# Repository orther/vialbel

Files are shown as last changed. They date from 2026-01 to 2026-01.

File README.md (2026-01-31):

# Vial Label Applicator

3D-printable semi-automated thermal label applicator for small vials. Applies wrap-around thermal labels (40mm x 20mm, NiimBot M2) to 3mL cylindrical vials (16mm diameter x 38.5mm tall).

## Key Specs

| Parameter | Value |
|---|---|
| Vial diameter | 16mm (22mm profile available) |
| Vial height | 38.5mm |
| Label size | 40mm x 20mm |
| Label position | 3mm from vial bottom |
| Material | ASA (Bambu Lab P1S) |
| Throughput | 2-3 seconds per vial |

## Project Structure

```
config.toml             - Parametric dimensions (profiles: default, 22mm)
src/                    - Parametric CAD scripts (Build123d, Python)
  config.py             - Config loader with profile support
  frame.py              - Main frame + assembly manifest generation
  peel_plate.py         - Label dispensing peel plate
  vial_cradle.py        - V-block vial holder
  tension_system.py     - Spool holder, dancer arm, guide roller bracket
  label_path.py         - Label routing simulation and validation
  validate_prints.py    - 3D print validation (manifold, overhang, wall thickness)
src/vcad/               - Parametric CAD scripts (vcad, Rust)
src/blender/            - Blender visualization and rendering
  import_assembly.py    - Import assembly via Blender MCP
  render_all.py         - Headless render script (3 camera presets)
models/
  components/           - Build123d-generated STL/3MF files
  vcad/                 - vcad-generated STL files
  assembly_manifest.json - Component positions (single source of truth)
  renders/              - Rendered assembly images
tests/                  - Integration tests (pytest)
.github/workflows/      - CI pipeline (Rust + Python + tests)
```

## Components

1. **Main Frame** — Base plate with mounting wall, pivot post, and mounting holes
2. **Peel Plate** — Label dispensing with 2mm radius peel edge
3. **Vial Cradle** — V-block holder with height positioning
4. **Tension System** — Spool holder, spring-loaded dancer arm, guide roller bracket
5. **Label Path** — Simulated routing: spool → dancer → guide → peel plate → vial

## Parametric Configuration

All dimensions are defined in `config.toml`. Switch vial sizes with profiles:

```bash
# Default 16mm vial
python src/peel_plate.py

# 22mm vial profile
python src/peel_plate.py --profile 22mm
```

Both Python (Build123d) and Rust (vcad) pipelines read from the same `config.toml`.

## Regenerating Models

### Build123d (precision parts)

```bash
python3 -m venv .venv && source .venv/bin/activate
pip install build123d

python src/frame.py              # Frame + assembly manifest
python src/peel_plate.py         # Peel plate
python src/vial_cradle.py        # Vial cradle
python src/tension_system.py     # Spool holder, dancer arm, guide roller bracket
python src/label_path.py         # Label path simulation + visualization STL
```

### vcad (rapid prototypes, Rust)

```bash
cargo run --manifest-path src/vcad/Cargo.toml
```

### Print Validation

```bash
pip install trimesh numpy rtree
python src/validate_prints.py
```

### Headless Rendering

```bash
blender --background --python src/blender/render_all.py -- \
    --output models/renders/ --resolution 1920x1080 --samples 128
```

Or use the convenience script:

```bash
./scripts/render.sh
```

## Testing

```bash
pip install pytest ruff
python -m pytest tests/ -v
```

Tests validate config loading, profile overrides, manifest structure, STL file existence, and code quality (ruff lint/format) — no build123d required.

## CI

GitHub Actions runs three jobs on push/PR to main:
- **Rust Check** — `cargo check` + `cargo clippy`
- **Python Lint** — `ruff check` + `ruff format --check`
- **Integration Tests** — pytest suite

## Documentation

- [Installation Guide](docs/installation-guide.md) — CAD environment setup
- [Print Settings](docs/print-settings.md) — Bambu Studio ASA profiles
- [Hardware BOM](docs/hardware-bom.md) — Non-printed parts list
- [Assembly Guide](docs/assembly-guide.md) — Step-by-step assembly
- [Calibration Guide](docs/calibration-guide.md) — First-time setup
- [Blender MCP Setup](docs/blender-mcp-setup.md) — Blender integration via MCP

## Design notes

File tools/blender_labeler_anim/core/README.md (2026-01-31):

# Core Modules

Shared infrastructure for the Blender label applicator animation system.

## Modules

- **constants.py** — Mechanical coordinates, radii, and label parameters
- **units.py** — Scene unit configuration (millimeters)
- **materials.py** — Material factory functions (label, backing, glass, metal)
- **cli.py** — CLI argument parsing for `blender -b -P script.py -- [args]`
- **render.py** — Render settings, output config, frame/animation rendering, MP4 encoding
- **generate_scene.py** — Base scene creation (camera, lights, ground, vial, rollers, CTRL empty)
- **geom_nodes_lib.py** — Geometry Nodes programmatic builders

## CTRL Empty

All animation is driven from custom properties on the `CTRL` empty:
- `feed_mm` — Label feed distance (0–200mm)
- `vial_rot_deg` — Vial rotation (0–360°)
- `dancer_deg` — Dancer arm angle (±30°)

## Usage

```python
import sys
sys.path.insert(0, '/path/to/tools/blender_labeler_anim')
from core.generate_scene import build_base_scene
from core.render import setup_render, render_animation
from core.cli import parse_args

args = parse_args()
objects = build_base_scene()
setup_render(engine=args.engine, samples=args.samples, resolution=tuple(args.resolution), fps=args.fps, frame_range=tuple(args.frames))
```

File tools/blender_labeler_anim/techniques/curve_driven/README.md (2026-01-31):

# Curve-Driven Label Routing

## What it demonstrates
The complete label/backing paper path through the applicator mechanism:
- Spool exit → dancer roller → guide roller → peel edge
- Peel separation: label continues to vial, backing wraps around peel radius and exits
- Feed visualization via curve trim/reveal driven by `CTRL.feed_mm`
- Dancer arm kinematics driven by `CTRL.dancer_deg`

## How it works
1. Waypoints from mechanical constants define the label path centerline
2. Roller wrap arcs are computed for dancer and guide rollers
3. At the peel edge, the path splits into backing exit and label exit curves
4. Geometry Nodes convert curves to ribbon meshes (Curve to Mesh + rectangle profile)
5. Trim/reveal GN modifier controls how much of each path is visible
6. Drivers on CTRL.feed_mm map feed distance to trim factor (0–1)

## How to run headless
```bash
blender -b -P tools/blender_labeler_anim/techniques/curve_driven/generate_and_render.py \
  -- --out tools/blender_labeler_anim/techniques/curve_driven/output \
  --frames 1 120 --fps 24 --samples 32
```

## Outputs
- `output/frame_0001.png` through `frame_0120.png` — rendered PNG frames
- `output/animation.mp4` — if `--encode-mp4` is passed and ffmpeg is available

## Key parameters
- `--frames 1 N` — number of frames (more = smoother, slower render)
- `--samples N` — Cycles samples (lower = faster, noisier)
- `--engine BLENDER_EEVEE_NEXT` — faster rendering alternative
- In script: modify `keyframe_ctrl()` to change animation timing

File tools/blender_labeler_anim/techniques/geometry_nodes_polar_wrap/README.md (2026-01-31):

# Wrap Technique B: Pure Geometry Nodes Polar Wrap

## What it demonstrates
A coordinate-space deformation that morphs a flat label strip into a cylindrical
wrap around the vial — entirely within Geometry Nodes, with no separate geometries.

## How it works
1. A flat, subdivided label mesh is created at the peel edge position
2. A Geometry Nodes modifier performs polar coordinate mapping:
   - Each vertex's X position (along the wrap direction) maps to an angle:
     `angle = (x / wrap_length) * wrap_max_angle * wrap_factor`
   - New positions computed relative to vial center:
     `x' = vial_cx + (r + eps) * cos(start_angle - angle)`
     `z' = vial_cz + (r + eps) * sin(start_angle - angle)`
     `y' = vial_cy + original_y`
3. A blend zone provides smooth transition from flat-at-peel to cylindrical:
   - Vertices near the current wrap front smoothly interpolate between flat and wrapped
   - Vertices beyond the wrap extent remain at the peel edge (or are hidden)
4. The `Wrap Factor` input (0–1) is driven by `CTRL.vial_rot_deg / 270`

## How to run headless
```bash
blender -b -P tools/blender_labeler_anim/techniques/geometry_nodes_polar_wrap/generate_and_render.py \
  -- --out tools/blender_labeler_anim/techniques/geometry_nodes_polar_wrap/output \
  --frames 1 120 --fps 24 --samples 32
```

## Outputs
- `output/frame_0001.png` through `frame_0120.png`
- `output/animation.mp4` (with `--encode-mp4`)

## Key parameters
- `Wrap Factor`: 0 = fully flat, 1 = fully wrapped (270°)
- `Blend Zone`: transition width in mm (default 5mm) — controls smoothness
- Surface offset: 0.3mm above vial radius
- Mesh resolution: 100 segments along wrap, 6 across width

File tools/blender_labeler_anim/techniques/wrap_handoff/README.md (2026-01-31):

# Wrap Technique A: Two-Geometry Handoff

## What it demonstrates
A deterministic "engineering visualization" of label wrapping using two separate
geometries: a flat label strip near the peel edge and a pre-shaped cylindrical
patch on the vial surface. As wrapping progresses, the wrapped patch is revealed
while the flat strip is hidden — creating the illusion of continuous wrapping.

## How it works
1. **Flat label strip**: A subdivided planar mesh positioned between the peel edge
   and vial contact point, with a slight arc for visual appeal.
2. **Wrapped label patch**: A cylindrical mesh pre-shaped to conform to the vial
   surface (offset 0.3mm above to avoid z-fighting), covering up to 270°.
3. **Handoff mechanism**: Geometry Nodes modifiers on each mesh use vertex index
   ratio as a position proxy. A Factor input (driven by `CTRL.vial_rot_deg`)
   controls which portions are visible:
   - Wrapped patch: vertices with index ratio < factor are kept (progressive reveal)
   - Flat strip: vertices with index ratio > factor are kept (progressive hide)
4. **Vial rotation**: The vial's Y rotation is driven by `CTRL.vial_rot_deg`,
   so the wrapped patch stays aligned as the vial turns.

## How to run headless
```bash
blender -b -P tools/blender_labeler_anim/techniques/wrap_handoff/generate_and_render.py \
  -- --out tools/blender_labeler_anim/techniques/wrap_handoff/output \
  --frames 1 120 --fps 24 --samples 32
```

## Outputs
- `output/frame_0001.png` through `frame_0120.png`
- `output/animation.mp4` (with `--encode-mp4`)

## Key parameters
- Wrap coverage: 270° (set in `constants.LABEL_WRAP_ANGLE`)
- Surface offset: 0.3mm above vial radius (prevents z-fighting)
- Mesh resolution: 80 segments around circumference, 4 along axis

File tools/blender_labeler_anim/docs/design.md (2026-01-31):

# Design: Blender Label Applicator Animation System

## Overview

A headless, scripted Blender animation system for visualizing a mechanical vial label applicator. The system generates all geometry, materials, and animation from Python scripts with no manual Blender interaction required.

## Architecture

### Core Layer (`core/`)
Shared infrastructure used by all techniques:
- **Scene generation**: Camera, lighting, ground plane, mechanical components (vial, rollers, peel plate)
- **CTRL Empty**: Single animation controller with `feed_mm`, `vial_rot_deg`, `dancer_deg` custom properties
- **Materials**: Principled BSDF-based materials for label, backing, glass, metal
- **Render pipeline**: Cycles/EEVEE-Next configuration, PNG output, optional MP4 encoding
- **Geometry Nodes library**: Programmatic node group construction (curve-to-ribbon, trim/reveal)

### Technique Layer (`techniques/`)
Three independent implementations, each self-contained:

1. **Curve-Driven** — Label/backing paths as Blender curves with ribbon mesh via GN
2. **Wrap Handoff** — Two-geometry system: flat strip near peel edge + cylindrical patch on vial
3. **Geometry Nodes Polar Wrap** — Pure GN coordinate deformation from flat to cylindrical

### Control Flow
```
CTRL.feed_mm ──► Curve trim/reveal ──► Label feed visualization
CTRL.vial_rot_deg ──► Vial rotation ──► Wrap amount (handoff or polar)
CTRL.dancer_deg ──► Dancer arm rotation ──► Tension arm kinematics
```

All motion is driven via Blender drivers referencing CTRL properties. No simulation or physics; fully deterministic.

## Determinism Guarantee

- No cloth/soft-body simulation
- No random seeds in geometry generation
- All positions computed from parametric equations
- Curves defined by explicit control points
- Geometry Nodes use deterministic operations only
- Repeated runs with same parameters produce identical output

## Coordinate System

- X: left(-) to right(+)
- Y: back(-) to front(+)
- Z: bottom(0) to top(+)
- Units: millimeters (scene scale = 0.001)

## Rendering

- Default engine: Cycles (GPU via Metal on macOS)
- Fallback: EEVEE-Next for faster previews
- Output: PNG frames with optional ffmpeg MP4 encoding
- Headless: `blender -b -P script.py -- [args]`

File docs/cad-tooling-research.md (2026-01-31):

# Programmatic CAD Tooling Research

**Date:** 2026-01-29
**Purpose:** Evaluate Python-scriptable, headless CAD tools for generating 3D-printable mechanical parts (peel plates, V-block cradles, spring-loaded tension arms, frames with heat-set insert recesses) targeting ASA on a Bambu Lab P1S.

**Key requirements:** Fillets/chamfers (2mm radius edges), clean STL/3MF export, fully headless operation, parametric design.

---

## Tool Comparison Matrix

| Criteria (1-5) | CadQuery | Build123d | SolidPython2 | OpenSCAD | FreeCAD (Python) |
|---|---|---|---|---|---|
| Headless/CLI reliability | 5 | 5 | 4 | 4 | 2 |
| Parametric design support | 5 | 5 | 4 | 4 | 4 |
| STL/3MF export | 5 | 5 | 3 | 3 | 4 |
| Fillets, chamfers, smooth curves| 5 | 5 | 2 | 2 | 5 |
| Boolean operations | 5 | 5 | 4 | 4 | 5 |
| Documentation quality | 4 | 4 | 3 | 4 | 3 |
| Ease of installation (pip) | 4 | 4 | 5 | 3 | 1 |
| Community/maintenance activity  | 4 | 4 | 2 | 4 | 5 |
| **Total** | **37** | **37** | **27** | **28** | **29** |

---

## Detailed Evaluation

### 1. CadQuery

**GitHub:** https://github.com/CadQuery/cadquery
**Install:** `pip install cadquery` (Python 3.9-3.12, 3.13 partial)
**Kernel:** Open CASCADE Technology (OCCT) via OCP bindings

**Pros:**
- Built from the ground up for headless, scriptable CAD -- no GUI dependency whatsoever
- Full BREP kernel (OCCT) provides native, high-quality fillets and chamfers on any edge
- Exports STL, STEP, 3MF, DXF, VRML, AMF natively
- Fluent/chained API for building parametric models
- Strong ecosystem: cq-kit, cqparts, CQ-editor for optional visualization
- Active development; pip-installable with binary wheels on all major platforms
- Tolerance control on STL tessellation for print quality tuning

**Cons:**
- Fluent/method-chaining API can be hard to debug -- stack traces are opaque
- String-based selectors (e.g., `">Z"`) lack IDE autocomplete
- cadquery-ocp wheels are large (~200MB) and only cover specific Python versions
- conda was historically the recommended install path; pip support is newer and occasionally has dependency issues

**Best for:** Production headless workflows, CI/CD pipelines, batch part generation

---

### 2. Build123d

**GitHub:** https://github.com/gumyr/build123d
**Install:** `pip install build123d` (Python 3.10-3.13)
**Kernel:** OCCT via the same OCP bindings as CadQuery

**Pros:**
- More Pythonic API than CadQuery -- uses context managers instead of method chaining
- Dual modeling: both builder-pattern (feature stack) and algebra-mode (CSG tree), combinable
- Enums replace string selectors -- full IDE autocomplete and type checking
- Native fillets/chamfers with intuitive edge selection (`group_by`, `filter_by`)
- STL and 3MF export via `Mesher` class with tolerance control
- Extensible via standard Python classes (no monkey-patching)
- Interoperable with CadQuery objects (shared OCP wrapper)
- Actively maintained by gumyr (original CadQuery contributor)

**Cons:**
- Younger project -- some APIs may still change
- Smaller community and fewer third-party examples than CadQuery
- Same large OCP binary wheel dependency
- Documentation is good but less battle-tested than CadQuery's

**Best for:** New projects where a modern, Pythonic API and strong IDE support matter

---

### 3. SolidPython2

**GitHub:** https://github.com/SolidCode/SolidPython
**Install:** `pip install solidpython2` (Python 3.7+)
**Kernel:** Generates OpenSCAD code; requires OpenSCAD installed for rendering

**Pros:**
- Trivial pip install (pure Python, no binary dependencies)
- Full Python language features for parametric design (loops, functions, classes)
- BOSL2 library integration for advanced shapes
- Lightweight -- just generates `.scad` files

**Cons:**
- **No native fillets/chamfers** -- inherits all of OpenSCAD's CGAL limitations
- Fillets require Minkowski sum (extremely slow on complex geometry) or manual construction
- Requires OpenSCAD as an external runtime dependency for STL export
- Only mesh-based export (STL); no STEP or native 3MF
- Low download numbers (188/week); beta status
- Two-step workflow: generate .scad, then invoke OpenSCAD to render
- OpenSCAD rendering can be very slow for complex models

**Best for:** Simple parts where OpenSCAD familiarity exists; not suitable for parts requiring fillets

---

### 4. OpenSCAD (Direct)

**Website:** https://openscad.org
**Install:** System package or download; no pip install
**Kernel:** CGAL (CSG-based)

**Pros:**
- Mature, well-documented scripting language purpose-built for parametric CAD
- Headless CLI mode: `openscad -o output.stl input.scad`
- Large community, many existing libraries (BOSL2, NopSCADlib, etc.)
- Customizer for parametric variants
- Good for simple mechanical parts and enclosures

**Cons:**
- **No native fillet or chamfer operations** -- fundamental limitation of CSG/CGAL kernel
- Workarounds (Minkowski sum) are impractical for complex geometry (hours/days to compute)
- Not Python -- custom language with limited programming constructs
- STL export only (no STEP, limited 3MF via external tools)
- Cannot represent smooth curves natively; everything is mesh-approximated from the start
- 2mm radius edge fillets on complex parts would be extremely difficult

**Best for:** Simple box/cylinder CSG parts; poor fit for parts needing fillets

---

### 5. FreeCAD (Python Scripting)

**GitHub:** https://github.com/FreeCAD/FreeCAD
**Install:** System install required; no pip install of the CAD kernel
**Kernel:** OCCT (same as CadQuery/Build123d)

**Pros:**
- Full professional CAD kernel with excellent fillet/chamfer/boolean support
- Massive feature set: PartDesign, Part, Draft, Sketcher, FEM, CAM
- Large, active community; well-funded open source project
- Can theoretically do anything a commercial CAD package can

**Cons:**
- **Headless operation is unreliable** -- many modules silently depend on GUI components
- May require `xvfb` (virtual framebuffer) on Linux for headless operation
- No pip install -- requires system FreeCAD installation and manual Python path configuration
- API is verbose and not Pythonic; documentation for scripting is scattered
- Different Python version between FreeCAD's bundled interpreter and your venv causes import errors
- Fragile setup for CI/CD or automated pipelines

**Best for:** Interactive CAD work with Python macros; poor fit for headless automation

---

## MCP Server Findings

Several MCP (Model Context Protocol) servers exist for CAD integration with AI assistants:

### FreeCAD MCP Servers

| Server | GitHub | Notes |
|---|---|---|
| **contextform/freecad-mcp** | https://github.com/contextform/freecad-mcp | Most feature-rich: 13 PartDesign ops (Pad, Fillet, Chamfer, Holes, Patterns) + 18 Part ops (Booleans, Transforms). Open source. |
| **neka-nat/freecad-mcp** | https://github.com/neka-nat/freecad-mcp | Control FreeCAD from Claude Desktop via uv. Simpler scope. |
| **lucygoodchild/freecad-mcp-server** | https://github.com/lucygoodchild/freecad-mcp-server | Basic geometry creation, booleans, document management. Cross-platform. |
| **bonninr/freecad_mcp** | https://github.com/bonninr/freecad_mcp | Claude/Cursor integration for prompt-assisted CAD design. |
| **jango-blockchained/mcp-freecad** | https://github.com/jango-blockchained/mcp-freecad | Multiple AI provider support, robust connection methods. |

### OpenSCAD MCP Servers

| Server | GitHub | Notes |
|---|---|---|
| **quellant/openscad-mcp** | https://github.com/quellant/openscad-mcp | Production-ready FastMCP server for OpenSCAD rendering. v1.0.0 (Aug 2025). |
| **jhacksman/OpenSCAD-MCP-Server** | https://github.com/jhacksman/OpenSCAD-MCP-Server | Text/image to 3D model generation. Multi-view reconstruction. 102 stars. |

### No CadQuery/Build123d MCP Servers Found

There are currently no MCP servers specifically for CadQuery or Build123d. However, since both are pure Python libraries, an MCP server wrapping them would be straightforward to build -- the LLM would generate CadQuery/Build123d Python code directly, which is already a well-documented pattern ("Text-to-CadQuery").

---

## Recommendation

### Primary: **Build123d**

Build123d is the strongest choice for this use case:

1. **Fillets/chamfers are first-class operations** -- 2mm radius edges on peel plates, smooth V-block cradle profiles, and rounded frame features are trivial with `fillet()` and `chamfer()` on selected edges.

2. **Fully headless** -- pure Python library, no GUI dependency, no xvfb hacks. Works in scripts, CI/CD, and automated pipelines.

3. **Clean export** -- native STL and 3MF export with tessellation tolerance control. 3MF is preferred for Bambu Lab P1S (Bambu Studio natively uses 3MF).

4. **Modern Pythonic API** -- context managers, enums, type hints, and IDE autocomplete make parametric design readable and maintainable. Dual builder/algebra modes suit different part design styles.

5. **Same OCCT kernel** as CadQuery and FreeCAD -- no compromises on geometric quality.

6. **pip installable** -- `pip install build123d` with binary wheels.

### Fallback: **CadQuery**

If Build123d's newer API causes issues or a specific feature is missing, CadQuery is a drop-in alternative sharing the same OCCT kernel. The ecosystem is larger and more battle-tested. Objects can be transferred between the two libraries.

### Not Recommended for This Use Case

- **SolidPython2/OpenSCAD** -- The lack of native fillets makes 2mm radius edges on complex parts impractical. The CGAL kernel cannot handle the geometry requirements.
- **FreeCAD scripting** -- Headless operation is too fragile for reliable automated part generation.

### MCP Integration Path

No existing MCP server covers CadQuery/Build123d, but building one would be straightforward since the tools are already Python-native. For immediate MCP-assisted CAD, **contextform/freecad-mcp** is the most capable option, though it requires a FreeCAD installation. The recommended approach is to use Build123d directly in Python scripts, potentially wrapping it in a custom MCP server later if conversational CAD design is desired.

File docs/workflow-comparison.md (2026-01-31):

# Workflow Comparison

Three CAD tools available for the vial label applicator project, each with different strengths.

## Tool Summary

| | Build123d | vcad | Blender MCP |
|---|---|---|---|
| **Role** | Precision parts | Rapid prototyping | Visualization & rendering |
| **Language** | Python | Rust | Python (bpy) |
| **Geometry** | BREP (exact) | Mesh (approximate) | Mesh + modifiers |
| **Fillets** | Native | None | Bevel modifier |
| **Export** | STL, 3MF | STL, GLB | Any format |
| **AI integration** | Script generation | Agent-friendly API | MCP server |
| **Maturity** | Production | v0.1.0 | Production |

## Recommended Workflow

### For manufacturing (3D printing)
Use **Build123d**. BREP geometry ensures exact dimensions. Fillets and precise edge treatments are critical for functional parts that need to fit together.

```
Build123d script → STL/3MF → Bambu Studio → Print
```

### For rapid iteration
Use **vcad**. Fast compile times, simple API. Good for testing layout changes and basic geometry before committing to Build123d precision scripts.

```
vcad Rust script → STL → Quick preview
```

### For visualization and rendering
Use **Blender MCP**. Import STL files from either tool, apply materials, set up lighting, and produce product renders — all driven by Claude.

```
Build123d/vcad → STL → Blender MCP import → Materials → Render
```

### Full pipeline
```
1. Prototype with vcad (quick geometry)
2. Refine with Build123d (precision parts)
3. Visualize with Blender MCP (renders, assembly views)
```

## File Locations

| Tool | Source | Output |
|---|---|---|
| Build123d | `src/*.py` | `models/components/` |
| vcad | `src/vcad/src/*.rs` | `models/vcad/` |
| Blender | `src/blender/*.py` | Via Blender MCP |

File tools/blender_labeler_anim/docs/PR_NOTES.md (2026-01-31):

# PR Notes

## chore/blender-labeler-core

### Summary
Core scaffolding for the Blender label applicator animation system.

### Changes
- Created `tools/blender_labeler_anim/` directory structure
- Implemented shared core modules:
  - `constants.py` — Mechanical coordinates and parameters
  - `units.py` — Scene unit configuration (mm)
  - `materials.py` — Material factories
  - `cli.py` — CLI argument parsing
  - `render.py` — Render configuration and execution
  - `generate_scene.py` — Base scene builder
  - `geom_nodes_lib.py` — Geometry Nodes helpers
- Added documentation: design.md, troubleshooting.md

### How to Run
```bash
# Verify core modules load in Blender
blender -b -P tools/blender_labeler_anim/core/generate_scene.py
```

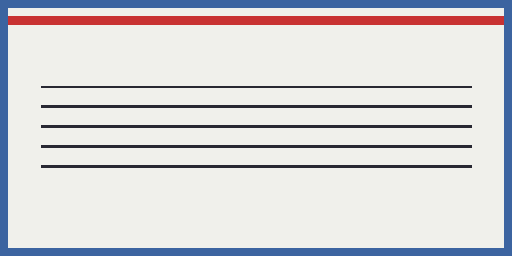
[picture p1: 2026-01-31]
tools/blender_labeler_anim/assets/label_texture.png

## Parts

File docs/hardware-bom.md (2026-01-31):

# Hardware Bill of Materials

All non-printed hardware required for assembly.

## Fasteners

| Item | Spec | Qty | Notes |
|---|---|-----|---|
| Socket head cap screw | M3 x 8mm | 8 | |
| Socket head cap screw | M3 x 12mm | 4 | |
| Heat-set insert | M3, 4mm OD x 5mm depth | 8 | McMaster 94459A130 or CNC Kitchen standard |
| Washer | M3 | 12 | |
| Hex nut | M3 | 4 | For adjustment slots |

## Springs

| Item | Spec | Qty | Notes |
|---|---|-----|---|
| Extension spring | ~6mm OD x 20mm length, light tension | 1 | For dancer arm |

## Bearings

| Item | Spec | Qty | Notes |
|---|---|-----|---|
| 608 bearing | 8mm ID x 22mm OD x 7mm | 2 | Dancer arm roller and guide roller |

## Pins

| Item | Spec | Qty | Notes |
|---|---|-----|---|
| Steel dowel pin | 8mm x 20mm | 2 | Bearing pins |
| Steel dowel pin | 8mm x 50mm | 1 | Dancer arm pivot |

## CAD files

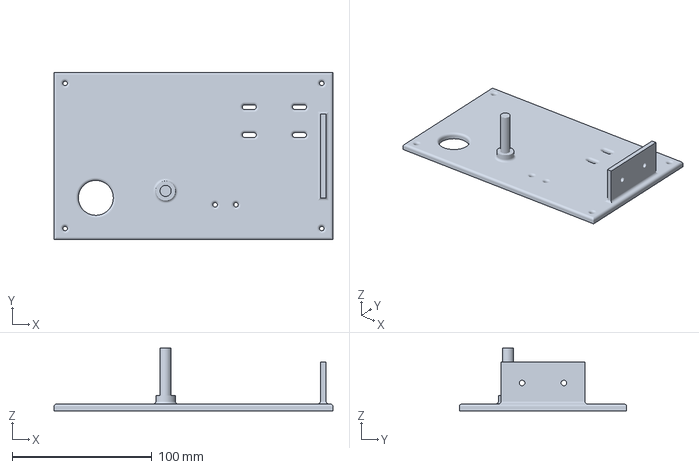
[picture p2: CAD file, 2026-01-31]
models/components/main_frame.3mf
200.0 x 120.0 x 45.0 mm

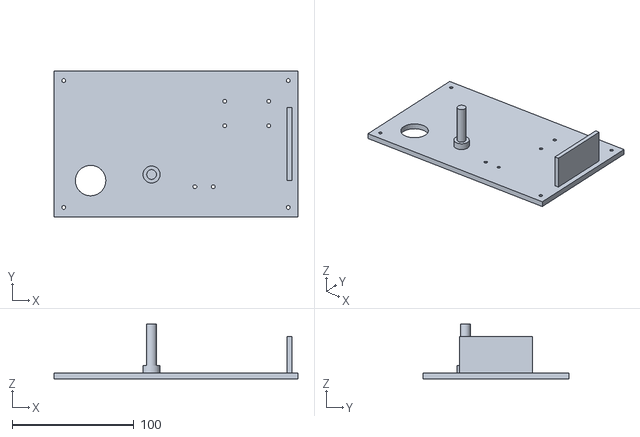
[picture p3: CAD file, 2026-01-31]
models/vcad/main_frame.stl
200.0 x 120.0 x 45.0

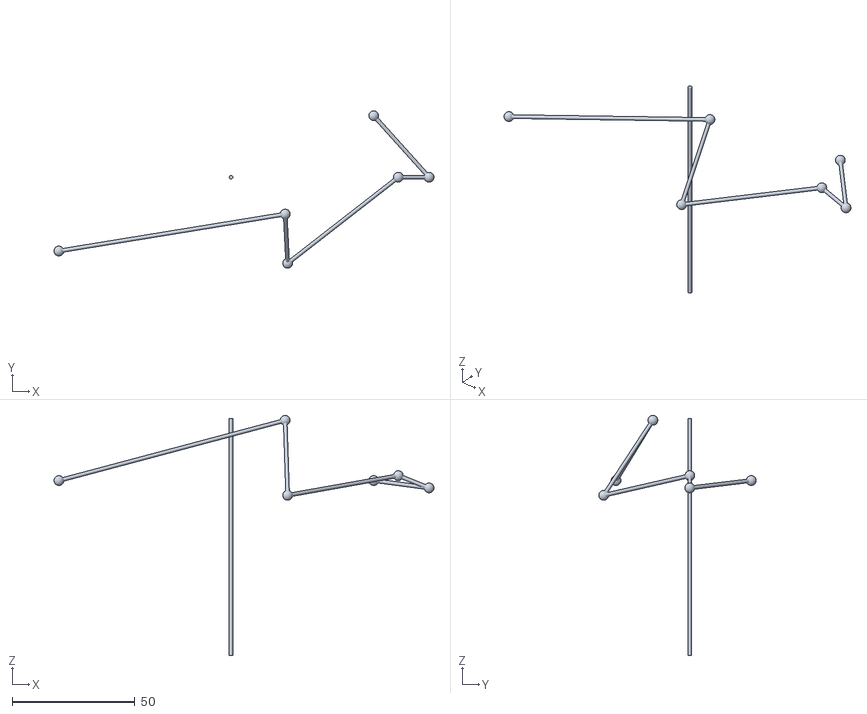
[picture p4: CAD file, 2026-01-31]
models/components/label_path.stl
154.5 x 64.0 x 97.7

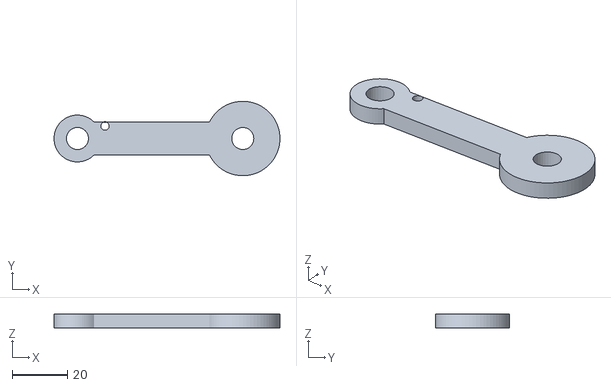
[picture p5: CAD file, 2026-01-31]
models/vcad/dancer_arm.stl
82.0 x 27.0 x 5.00

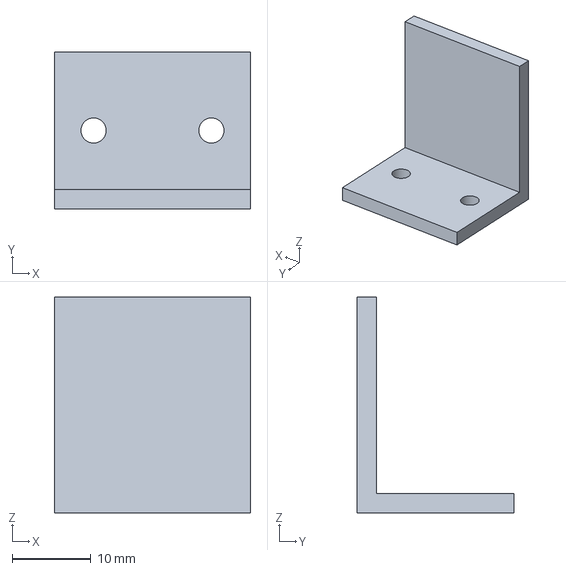
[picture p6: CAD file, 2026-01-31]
models/components/guide_roller_bracket.3mf
25.0 x 20.0 x 27.5 mm

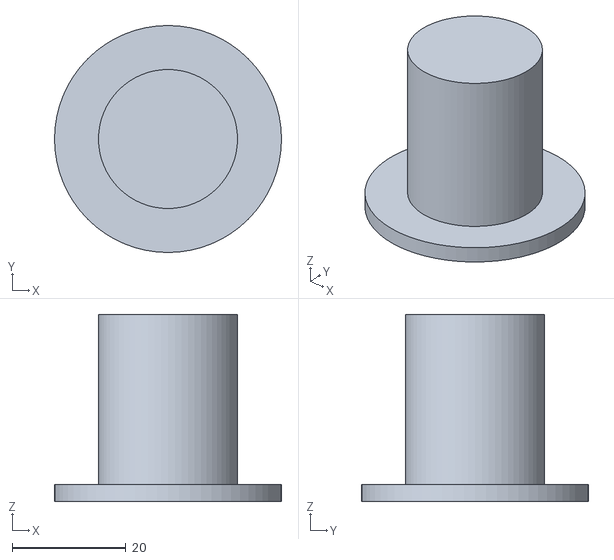
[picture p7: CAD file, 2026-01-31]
models/vcad/spool_holder.stl
40.0 x 40.0 x 33.0

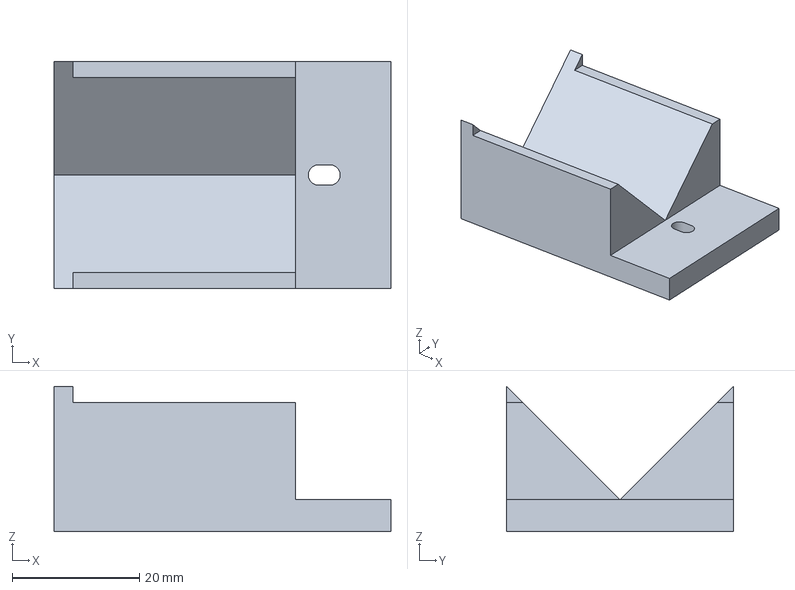
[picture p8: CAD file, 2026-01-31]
models/components/vial_cradle.3mf
53.0 x 35.6 x 22.8 mm

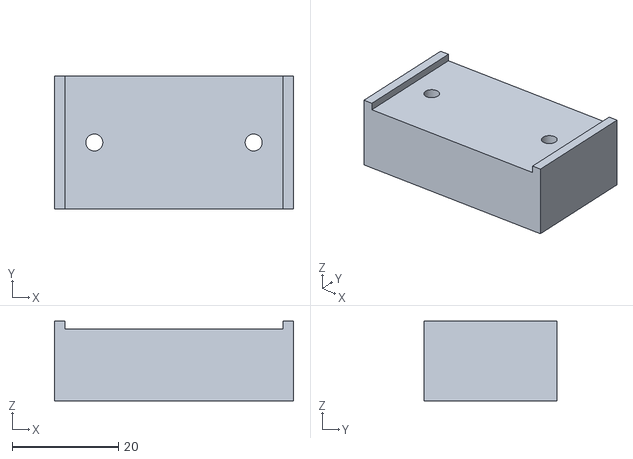
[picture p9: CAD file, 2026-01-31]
models/vcad/peel_plate.stl
45.0 x 25.0 x 15.0

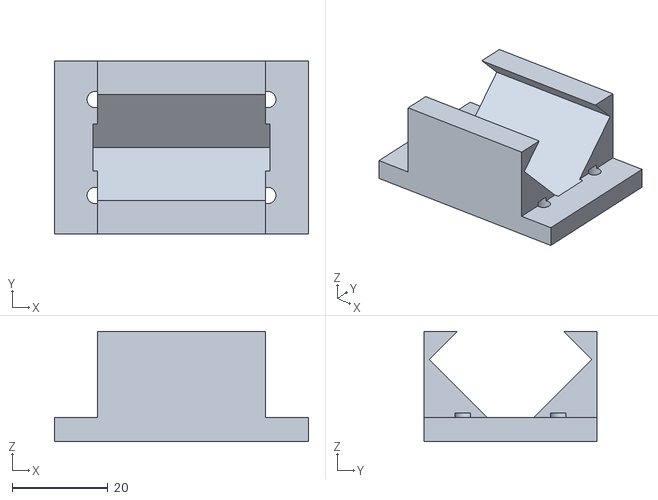
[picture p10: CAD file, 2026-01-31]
models/vcad/vial_cradle.stl
53.0 x 36.0 x 23.0

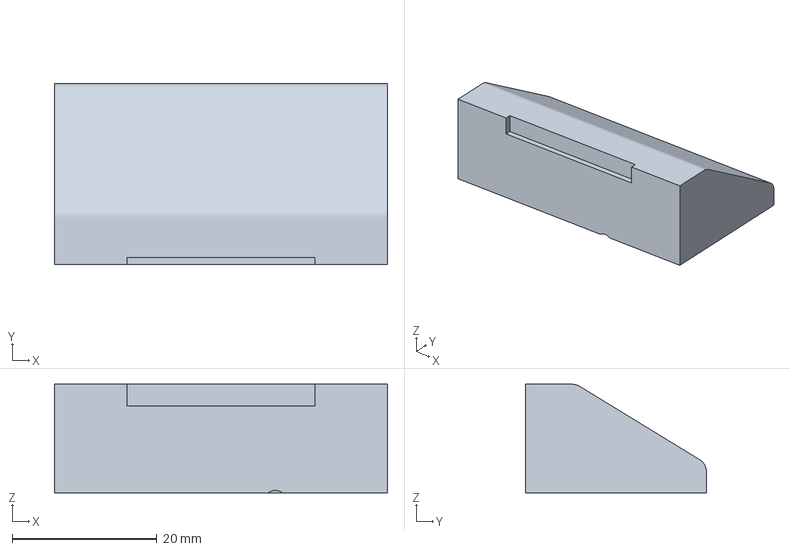
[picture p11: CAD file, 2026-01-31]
models/components/peel_plate.3mf
46.0 x 25.0 x 15.0 mm

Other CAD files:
models/vcad/guide_roller_bracket.stl
models/components/spool_holder.3mf
models/components/dancer_arm.stl
models/components/guide_roller_bracket.stl
models/components/peel_plate.stl
models/components/spool_holder.stl
models/components/vial_cradle.stl

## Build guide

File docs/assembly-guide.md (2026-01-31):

# Assembly Guide

## Prerequisites

- All parts printed per [print-settings.md](print-settings.md)
- All hardware from [hardware-bom.md](hardware-bom.md)
- Soldering iron with M3 insert tip

## Steps

### 1. Install Heat-Set Inserts

Set soldering iron to 220C (appropriate for ASA). Press each M3 heat-set insert into the frame mounting holes. Allow to cool before proceeding.

### 2. Mount Spool Holder

Attach the spool holder to the frame base using M3 x 8mm screws.

### 3. Install Dancer Arm Pivot

Press the 8mm x 50mm steel dowel pin into the dancer arm pivot hole on the frame.

### 4. Attach Dancer Arm

Slide the dancer arm onto the pivot pin. Install the 608 bearing on an 8mm x 20mm dowel pin and insert into the dancer arm roller position. Attach the extension spring between the dancer arm and the frame anchor point.

### 5. Mount Guide Roller Bracket

Install the second 608 bearing on the remaining 8mm x 20mm dowel pin. Mount the guide bracket to the frame using M3 x 12mm screws and washers.

### 6. Mount Peel Plate

Attach the peel plate to the frame wall using M3 x 8mm screws.

### 7. Position Vial Cradle

Place the vial cradle on the adjustment slots. Secure loosely with M3 x 12mm screws, hex nuts, and washers. Final position is set during calibration.

### 8. Thread Label Path

Route the label backing paper through the following path:

```
Spool --> Dancer arm roller --> Guide roller --> Peel plate
```

The label face should be oriented outward (away from the peel plate surface) so labels separate at the peel edge.

### 9. Test

Feed a label strip through the path and verify smooth travel before loading a full spool. Proceed to [calibration-guide.md](calibration-guide.md).

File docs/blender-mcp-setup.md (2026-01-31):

# Blender MCP Setup

Connect Blender to Claude Code for AI-driven 3D visualization, assembly, and rendering.

## Prerequisites

- Blender 4.0+ (installed via `brew install --cask blender`)
- Python 3.10+ with `uvx` (`pip install uv` or `brew install uv`)

## 1. Add MCP Server to Claude Code

```bash
claude mcp add blender -- uvx blender-mcp
```

This registers the blender-mcp server so Claude can call Blender tools.

## 2. Install Blender Addon

1. Download `addon.py` from [blender-mcp](https://github.com/ahujasid/blender-mcp)
2. Open Blender → Edit → Preferences → Add-ons
3. Click "Install..." and select the downloaded `addon.py`
4. Enable the checkbox for "Interface: Blender MCP"

## 3. Connect

1. Open Blender
2. Press `N` to open the sidebar → find the "BlenderMCP" tab
3. Click "Connect to Claude"
4. Start a Claude Code session — Blender tools will be available

## Available Tools

| Tool | Description |
|---|---|
| `execute_blender_code` | Run arbitrary Python/bpy code in Blender |
| `get_scene_info` | Get current scene objects and properties |
| `get_object_info` | Get details about a specific object |
| `get_viewport_screenshot` | Capture current viewport as image |
| `set_material` | Apply materials to objects |
| `get_polyhaven_assets` | Browse PolyHaven material/model library |

## Workflow Scripts

Two scripts in `src/blender/` are designed to be executed via `execute_blender_code`:

- **`import_assembly.py`** — Imports all STL components at correct assembly positions with color-coded materials
- **`render_setup.py`** — Sets up camera, three-point lighting, and Cycles render settings for product photography

## Usage Example

From Claude Code, after Blender is connected:

1. Ask Claude to import the assembly: executes `import_assembly.py` via MCP
2. Ask Claude to set up rendering: executes `render_setup.py` via MCP
3. Ask Claude to capture a screenshot: uses `get_viewport_screenshot`
4. Ask Claude to modify materials or positions: uses `execute_blender_code`

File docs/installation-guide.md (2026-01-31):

# Installation Guide

## Requirements

- Python 3.10+ (tested with 3.13)
- pip

## Setup

```bash
python3 -m venv .venv
source .venv/bin/activate
pip install build123d
```

## Verify

```bash
python src/test_cad_setup.py
```

Should output bounding box dimensions and export STL/3MF files to `models/test/`.

## Tooling

- **Build123d** (v0.10.0) - Parametric CAD library using OCCT kernel
- Exports STL and 3MF (native format for Bambu Studio)
- See [cad-tooling-research.md](cad-tooling-research.md) for selection rationale

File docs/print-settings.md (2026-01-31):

# Print Settings

Bambu Studio profile for ASA filament on a Bambu Lab P1S.

## Layer and Structure

| Setting | Functional Parts | Non-Critical Parts |
|---|---|---|
| Layer height | 0.20mm | 0.28mm |
| Walls | 4 minimum | 4 minimum |
| Infill | 40% gyroid | 20% gyroid |

## Adhesion and Enclosure

- **Brim**: Enabled, 5mm width for warping prevention
- **Enclosure**: Required for ASA (P1S enclosure panels must be installed)

## Temperature

| Setting | Range | Recommended |
|---|---|---|
| Nozzle | 240-260C | 250C |
| Bed | 100-110C | 105C |

## Speed and Cooling

- **Print speed**: 60-80mm/s
- **First layer speed**: 20mm/s
- **Part cooling fan**: 30-50% after first layer

## ASA Shrinkage

ASA shrinks 0.4-0.7% during cooling. All part dimensions in this project account for this shrinkage. Do not apply additional scaling in the slicer.

## Print Orientation by Component

| Component | Orientation | Notes |
|---|---|---|
| Peel plate | Flat side down | Peel edge faces up for smooth finish |
| Vial cradle | V-groove facing up | |
| Spool holder | Flange down | |
| Dancer arm | Flat on bed | |
| Guide bracket | L-shape vertical wall up | |
| Main frame | Flat base down | May need to split if exceeding 256mm build volume |

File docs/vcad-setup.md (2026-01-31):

# vcad Setup

Rust-based parametric CSG modeling for rapid prototyping of vial applicator components.

## Prerequisites

- Rust toolchain (install via `curl --proto '=https' --tlsv1.2 -sSf https://sh.rustup.rs | sh`)
- CMake and Ninja (`brew install cmake ninja`)

## Building

```bash
cargo build --manifest-path src/vcad/Cargo.toml
```

## Generating Models

```bash
cargo run --manifest-path src/vcad/Cargo.toml
```

Outputs STL files to `models/vcad/`:
- `peel_plate.stl` — Simplified peel plate (box body, no wedge profile or fillets)
- `vial_cradle.stl` — V-block cradle with angled cut
- `main_frame.stl` — Base plate with wall, pivot post, mounting holes

## vcad vs Build123d

| Feature | vcad | Build123d |
|---|---|---|
| Language | Rust | Python |
| Kernel | Manifold (mesh) | OCCT (BREP) |
| Fillets | No native support | Full BREP fillets |
| Precision | Mesh approximation | Mathematically exact |
| Export | STL, GLB, USD, STEP | STL, 3MF, STEP |
| AI workflow | Designed for agents | Standard Python |

## Limitations

- No native fillets or chamfers (mesh-based geometry)
- No loft or sweep operations
- V-groove approximated with rotated box cut (not trigonometric profile)
- Mounting slots simplified to round holes
- v0.1.0 — early-stage library with limited documentation

## Project Structure

```
src/vcad/
├── Cargo.toml          # Dependencies (vcad 0.1.0)
├── src/
│   ├── main.rs         # Entry point, builds all components
│   ├── peel_plate.rs   # Peel plate CSG
│   ├── vial_cradle.rs  # Vial cradle CSG
│   └── frame.rs        # Main frame CSG
```

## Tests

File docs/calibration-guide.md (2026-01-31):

# Calibration Guide

First-time setup after assembly. Refer to [assembly-guide.md](assembly-guide.md) if not yet assembled.

## 1. Adjust Vial Cradle Position

Slide the vial cradle along its adjustment slots until the label exit point on the peel plate aligns with the vial surface when a vial is seated in the cradle. Tighten the M3 hex nuts once positioned.

## 2. Adjust Dancer Arm Spring Tension

The spring should be:
- **Light enough** to allow the backing paper to feed freely without excessive drag.
- **Firm enough** to maintain consistent tension and prevent slack in the label path.

If the spring is too stiff, hook it to a lower anchor point or replace with a lighter spring.

## 3. Test Label Peel

Feed backing paper through the full path. Pull the backing paper past the peel plate edge and verify that labels separate cleanly from the backing at the peel edge. If labels do not peel, check that:
- The peel plate edge is sharp and smooth (sand lightly if needed).
- The backing paper wraps tightly around the peel edge with sufficient angle.

## 4. Height Check

Place a vial in the cradle. Verify that the bottom edge of the presented label sits approximately 3mm from the bottom of the vial. Adjust cradle position vertically if needed.

## 5. Width Check

Verify that the label tracks centered within the peel plate channel. If the label drifts to one side, adjust the guide roller bracket alignment.

## 6. Practice Technique

1. Place a vial into the cradle.
2. Roll the vial against the presented label at the peel plate edge.
3. Continue rotating the vial to wrap the label fully around.

Run through several labels to confirm consistent placement before labeling production vials.

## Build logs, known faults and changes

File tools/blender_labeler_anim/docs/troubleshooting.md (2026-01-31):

# Troubleshooting

## Common Issues

### "No module named 'core'"
Ensure the script adds the parent directory to sys.path:
```python
import sys
from pathlib import Path
sys.path.insert(0, str(Path(__file__).resolve().parent.parent))
```

### GPU rendering fails in headless mode
- Check `blender --version` supports Metal (macOS) or OptiX/CUDA (Linux/Windows)
- Fallback: use `--engine BLENDER_EEVEE_NEXT` or set Cycles to CPU

### Geometry Nodes not applying
- Ensure the modifier's `node_group` is set before accessing inputs
- Check that socket types match (Float vs Vector, etc.)

### Driver not updating
- After adding drivers programmatically, call:
  ```python
  bpy.context.view_layer.update()
  bpy.app.handlers.depsgraph_update_post.clear()  # if stuck
  ```

### Blender 5.0 API changes
- `bpy.data.node_groups.new()` type is `'GeometryNodeTree'` (not `'GEOMETRY_NODES'`)
- Interface sockets use `tree.interface.new_socket()` instead of `tree.inputs.new()`
- Action/fcurve API has changed; prefer drivers over keyframed actions where possible

### ffmpeg not found
- Install via `brew install ffmpeg` (macOS) or package manager
- Or skip MP4 encoding: omit `--encode-mp4` flag

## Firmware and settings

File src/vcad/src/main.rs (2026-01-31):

//! Vial label applicator components built with vcad.
//!
//! Generates simplified versions of each component as STL files.
//! These lack BREP fillets (vcad is mesh-based) but are suitable for
//! Blender MCP import and rapid prototyping.

mod config;
mod dancer_arm;
mod frame;
mod guide_roller_bracket;
mod peel_plate;
mod spool_holder;
mod vial_cradle;

fn main() {
    let output_dir = "../../models/vcad";
    std::fs::create_dir_all(output_dir).expect("Failed to create output directory");

    let cfg = config::load_config();

    println!("Building vcad components...\n");

    type BuildFn = Box<dyn Fn(&config::Config) -> vcad::Part>;
    let components: Vec<(&str, BuildFn)> = vec![
        ("peel_plate", Box::new(peel_plate::build)),
        ("vial_cradle", Box::new(vial_cradle::build)),
        ("main_frame", Box::new(frame::build)),
        ("spool_holder", Box::new(spool_holder::build)),
        ("dancer_arm", Box::new(dancer_arm::build)),
        ("guide_roller_bracket", Box::new(guide_roller_bracket::build)),
    ];

    for (name, build_fn) in &components {
        let part = build_fn(&cfg);
        let path = format!("{}/{}.stl", output_dir, name);
        part.write_stl(&path)
            .unwrap_or_else(|e| panic!("Failed to write {} STL: {}", name, e));
        println!("Exported: {}", path);
    }

    println!("\nAll vcad components built.");
}

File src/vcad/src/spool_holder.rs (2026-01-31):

//! Spool holder — simplified CSG version.
//!
//! The Build123d version uses precise cylinders with mounting holes.
//! This vcad version approximates the shape with cylinder primitives
//! and boolean operations.

use vcad::*;

use crate::config::Config;

pub fn build(cfg: &Config) -> Part {
    // Base flange
    let flange = centered_cylinder("flange", cfg.spool_flange_diameter / 2.0, cfg.spool_flange_thickness, 64);

    // Spindle on top of flange
    let spindle = centered_cylinder("spindle", cfg.spool_spindle_od / 2.0, cfg.spool_height, 64)
        .translate(0.0, 0.0, (cfg.spool_flange_thickness + cfg.spool_height) / 2.0);

    // M3 mounting hole through center
    let hole = centered_cylinder("hole", cfg.mount_hole_diameter / 2.0, cfg.spool_flange_thickness + 2.0, 32);

    (flange + spindle) - hole
}

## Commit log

2026-01-30 Initialize project scaffold for vial label applicator
    Set up directory structure for parametric CAD scripts, generated models,
    documentation, and reference materials. Add README with project overview
    and key specifications.
2026-01-30 Add CAD tooling research and Build123d setup
    Research evaluated CadQuery, Build123d, SolidPython2, OpenSCAD, and FreeCAD.
    Selected Build123d for native fillet/chamfer support via OCCT kernel,
    headless operation, and Pythonic API. Verified STL and 3MF export.
    [test_cylinder.3mf, test_cylinder.stl]
2026-01-30 Add peel plate, vial cradle, and tension system components
    Peel plate: wedge-shaped body with 2mm radius peel edge, 41mm label
    channel with guide rails, M3 mounting holes (46x25x15mm).
    Vial cradle: 90-degree V-block for 16mm vials with height stop wall
    and M3 mounting slots for position adjustment (53x36x23mm).
    Tension system: spool holder (24.5mm spindle, 40mm flange), dancer
    arm (60mm with pivot/bearing bores), L-shaped guide roller bracket.
    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
    [dancer_arm.stl, guide_roller_bracket.3mf, guide_roller_bracket.stl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]
2026-01-30 Add main frame, assembly visualization, and documentation
    Main frame (200x120x45mm) integrates all components with adjustment
    slots, heat-set insert holes, pivot post, and spool mount. Assembly
    STL shows all components positioned on the frame.
    Documentation: print settings (ASA/P1S), hardware BOM, assembly
    guide, and calibration guide.
    [main_frame.3mf]
2026-01-30 Add vcad and Blender MCP integration
    - Add vcad Rust project with simplified CSG components (peel plate,
    vial cradle, main frame) exporting to models/vcad/
    - Add Blender MCP workflow scripts for assembly import and render setup
    - Configure blender-mcp server for Claude Code integration
    - Add documentation for Blender MCP setup, vcad setup, and workflow
    comparison between Build123d, vcad, and Blender
    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
    [main_frame.stl, peel_plate.stl, vial_cradle.stl]
2026-01-30 Add product renders and gitignore CLAUDE.md files
    Rendered assembly visualizations from Blender MCP pipeline:
    hero shot, top view, front detail, and product shot angles.
2026-01-31 Fix vcad edition, add missing tension components, fix pi constant
    - Fix Cargo.toml edition from invalid "2024" to "2021"
    - Add spool_holder.rs, dancer_arm.rs, guide_roller_bracket.rs
    to match all 6 Build123d components
    - Refactor main.rs to use component loop for cleaner exports
    - Replace hardcoded 3.14159 with math.radians() in Blender script
    [main.rs, spool_holder.rs]
2026-01-31 Stage 1: Cleanup test artifacts, regenerate all vcad STLs
    - Remove models/test/ directory and test_cad_setup.py
    - Generate all 6 vcad STLs (added spool_holder, dancer_arm, guide_roller_bracket)
    - Simplify dancer_arm 3MF export fallback (known Build123d mesh limitation)
    - Add implementation plan for remaining stages
    - Gitignore .claude/ local settings
    [dancer_arm.stl, guide_roller_bracket.3mf, guide_roller_bracket.stl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]
2026-01-31 Stage 2: Add label path simulation with constraint validation
    Define physical label routing from spool through dancer, guide roller,
    peel plate, and onto vial surface. Validates bend radii, path length
    (304mm), and clearances. Generates 3D path visualization STL.
    [label_path.stl]
2026-01-31 Stage 3: Add parametric config system with 22mm vial profile
    Create config.toml with all component dimensions and a 22mm vial
    profile override. Add src/config.py loader that merges profiles.
    Refactor all 5 CAD scripts to source parameters from config.
    Default profile produces identical output to hardcoded values.
    22mm profile scales all components appropriately.
    [guide_roller_bracket.3mf, main_frame.3mf, peel_plate.3mf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]
2026-01-31 Stage 4: Extract assembly positions into shared manifest
    Add get_component_positions() to frame.py that derives all component
    positions from frame geometry. Generate assembly_manifest.json as
    single source of truth. Blender import script now reads from manifest
    instead of hardcoded positions.
    [main_frame.3mf]
2026-01-31 Stage 5+7: Add print validation and headless Blender render scripts
    validate_prints.py: Checks manifold, overhang (50% threshold), and
    wall thickness via trimesh ray casting. 5/6 components pass; dancer_arm
    fails manifold due to known Build123d sketch union limitation.
    render_all.py: Headless Blender rendering with 3 camera presets
    (hero, top, front), Cycles engine, sun+area lighting. Reads component
    positions from assembly_manifest.json. Run via scripts/render.sh.
2026-01-31 Stage 6: Add CI pipeline with Rust check and Python lint
    GitHub Actions workflow with two jobs:
    - rust-check: cargo check + clippy on src/vcad/
    - python-lint: ruff check + format on all Python scripts
    Add ruff.toml to suppress F403/F405 for Build123d star imports.
    Fix unused imports and format all Python files.
2026-01-31 Fix PR review issues: manifest-driven positions, config cleanup, error handling
    - label_path.py: read component positions from assembly_manifest.json
    instead of recomputing them (single source of truth)
    - label_path.py: move pivot_post_height to config.toml
    - validate_prints.py: load component list from manifest with fallback
    - render_all.py: add resolution format validation
    - tension_system.py: fix redundant exception clause
    - import_assembly.py: remove always-true debug guard
    - Remove IMPLEMENTATION_PLAN.md (all stages complete)
2026-01-31 Fix dancer_arm non-manifold mesh by using 3D primitive fusion
    Replace 2D sketch union (Circle+Circle+Rectangle) with direct 3D
    primitive addition (Cylinder+Cylinder+Box). The sketch approach
    produced non-manifold edges that caused 3mf export to fail.
2026-01-31 Read vcad component dimensions from shared config.toml
    Add toml/serde config loader so Rust vcad components use the same
    parametric values as the Python Build123d scripts. Eliminates
    duplicated constants across the two CAD pipelines.
2026-01-31 Fix Blender headless rendering: camera framing, mm-to-m scale, deprecation
    - Add obj.scale=(0.001,0.001,0.001) so mesh vertices are properly in
    meters for Blender world space (fixes bounding box and camera framing)
    - Update camera presets and use 35mm lens for better assembly coverage
    - Force depsgraph update before computing assembly center
    - Remove deprecated use_nodes=True calls (Blender 5.0+ always has nodes)
    - Apply same scale fix to import_assembly.py for MCP consistency
2026-01-31 Add integration tests for config, manifest, and code quality
    15 pytest tests covering config loading, profile overrides, manifest
    structure validation, STL file existence, and ruff lint/format checks.
    No build123d dependency required — suitable for CI.
2026-01-31 Add integration tests job to CI pipeline
    New integration-tests job runs pytest suite that validates config
    loading, assembly manifest structure, STL file existence, and code
    quality checks — all without requiring build123d.
2026-01-31 Update README with config profiles, rendering, validation, testing, and CI
    Rewrite to document the full pipeline: parametric config system,
    label path simulation, print validation, headless Blender rendering,
    pytest integration tests, and GitHub Actions CI.
2026-01-31 Add config validation with range and cross-field checks
    Catch invalid dimensions before CAD generation to prevent
    wasted print time. Validates required keys, numeric types,
    physical ranges, and dimensional relationships.
2026-01-31 Improve render quality with studio lighting and better materials
    Add HDRI environment (Polyhaven brown_photostudio_02) with fallback
    3-point lighting, per-component material properties (metallic frame,
    matte printed parts), shadow catcher ground plane, depth of field for
    hero shots, and additional camera presets (isometric, side, detail peel).
    Use EEVEE for fast previews when samples < 32, Cycles for quality.
2026-01-31 Improve render quality with studio lighting and better materials
    - Replace sun+area lights with 3-point lighting (warm key, cool fill, rim)
    - Add procedural gradient sky world background
    - Add MATERIAL_OVERRIDES dict for per-component material properties
    (metallic aluminum frame, matte PLA printed parts)
    - Make ground plane a shadow catcher with transparent film
    - Expand from 3 to 6 camera presets (hero, isometric, front, side, top, detail_peel)
    - Auto-fit camera distance from assembly bounding box (70% frame fill)
    - Add depth of field support on hero and detail shots
    - Use Cycles for samples >= 32, EEVEE for lower counts
2026-01-31 Replace Build123d Mesher 3MF export with Blender-based pipeline
    Remove inline Mesher() 3MF export from all CAD scripts (frame.py,
    peel_plate.py, tension_system.py, vial_cradle.py). CAD scripts now
    export STL only. 3MF conversion is handled by a dedicated Blender
    script (export_3mf.py) that imports STLs and re-exports as 3MF,
    producing reliable manifold meshes.
2026-01-31 Fix 3MF export: use trimesh instead of Blender
    Blender 5.0+ removed the built-in 3MF add-on, so
    bpy.ops.export_mesh.threemf no longer exists. Replace with trimesh
    which is lightweight and handles STL→3MF conversion reliably.
    Add scripts/export_3mf.sh wrapper using uvx for dependency management.
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2026-01-31 Add two-geometry handoff wrap technique
    Implements deterministic label wrapping using a flat label strip near the
    peel edge and a pre-shaped cylindrical patch on the vial surface. GN-based
    reveal/hide masks driven by CTRL.vial_rot_deg create the handoff illusion.
    Vial rotation driven via driver. Surface offset prevents z-fighting.
    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
